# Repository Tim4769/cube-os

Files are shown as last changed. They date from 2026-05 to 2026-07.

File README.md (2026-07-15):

# Cube OS

## Members

- Tim
- Pat
- Taiyo

## Description

Cube OS is a desktop robot of 80 x 80 x 80 mm controlled by two legs. It can walk and communicate with other Cube OS robots through online servers using a custom PCB with an ESP32 microcontroller. It supports voice messages, text messages, and remote control features, helping friends stay connected even when they are far apart.

## Features

- Wi-Fi communication between robots via an online server.
- Two 9 g servos power a four-bar walking linkage for bipedal locomotion.
- IMU-assisted stepping, turning, fall detection, and recovery for inertial gait control.
- Ambient Rest Mode with light-aware quiet, privacy, and do-not-disturb behavior.
- Desk climate sensing for local humidity and temperature data.
- Voice Mailbox using the integrated microphone and speaker to record and replay voice notes from friends.
- USB-C power workflow for battery-powered operation, serial debugging, charging, and flashing.
- Camera sharing with OV2640 pictures or brief videos sent to friends or the dashboard.
- Four-face display OS with widgets, expressions, friend feeds, time, status, and air data.
- Remote control so friends can control another Cube OS and interact from far away.

## Justification

Some of our team members are graduating from high school and heading to college after 7 years together at the same school, and we thought, why do not we build something to keep our connection more real and maintain our friend group? Social media and group chats alone make it hard to keep the connection physical, and we will not always have time to fly to each other's cities to meet.

With Cube OS, we aim to keep annoying each other like we used to, in a friendly manner, by controlling each other's robots and sending random noises and messages at 2 am, like crashing into each other's dorm rooms as we used to. With its extra features, it can also serve as a handy desktop companion for productivity or just an accessory for your desk.

## BOM Breakdown

| Item | Qty | Estimate |
| --- | ---: | ---: |
| PCB, minimum production amount | 2 | 144 USD |
| 9 g micro servo motors | 2 | 8 USD |
| OV2640 camera | 1 | 5 USD |
| AS02504AR speaker | 1 | 5 USD |
| 1S 3.7 V LiPo battery | 1 | 6 USD |
| ER-TFT1.54-2 display panels | 4 | 24 USD |
| **Total** |  | **192 USD** |

## Current Status Photos

Mechanical linkage current status

Current mechanical linkage prototype.

PCB current status

Current PCB layout and component placement.

Assembled Cube OS Rev A PCB current status

Current assembled Rev A PCB during USB, firmware, and Wi-Fi power bring-up.

## Project Files

Short index of the main current files. Directory paths, placeholder files, metadata files, scaffold code, TODO files, and planning notes are intentionally excluded.

- PCB source: `PCB/Rev A/source/Cube OS/Cube OS.kicad_pro`, `PCB/Rev A/source/Cube OS/Cube OS.kicad_sch`, `PCB/Rev A/source/Cube OS/Cube OS.kicad_pcb`
- PCB fabrication package: `PCB/Rev A/gerbers/Gerber.zip`, `PCB/Rev A/production/BOM.csv`, `PCB/Rev A/production/CPL.csv`, `PCB/Rev A/production/fabrication_notes.md`
- PCB order package: `PCB/Rev A/order/BOM_manufacture.xls`, `PCB/Rev A/order/ordering contract.pdf`
- PCB 3D export and linked models: `PCB/Rev A/3d_models/PCB 3d model.step`, `PCB/Rev A/source/Cube OS/3D models/`
- Firmware bring-up: `Firmware/platformio.ini`, `Firmware/src/main.cpp`, `Firmware/src/config.h`, `Firmware/src/`
- Sourcing and budget: `BOM/bom.csv`, `BOM/sourcing_notes.md`
- Mechanical assembly: `CAD/Legs/Linkage V2/Assembly/Stepping foot linkage prototype v2.step`
- Current status photos: `Media/Mechanical status 20260511222505_905_44.jpg`, `Media/PCB status 2026-05-28 at 6.02.45 PM.png`, `Media/PCB status 2026-07-15 at 9.23.13 PM.jpg`

## Git LFS

Large binary project assets are tracked with Git LFS through `.gitattributes`, including status photos, CAD/STEP exports, Gerber/drill manufacturing files, archives, PDFs, and spreadsheet order records.

## Placeholder, Scaffold, And Planning Content

These paths are not listed as active project files because they currently contain placeholder files, metadata files, TODO-only files, scaffold code, or planning notes. There is no final project content inside them yet.

- `Software/`
- `Software/src/`
- `Software/screenshots/`

Also excluded from the active project list: `CAD/Legs/Linkage V2/Components/Placeholder Bar.step`.

## License

MIT. See `LICENSE`.

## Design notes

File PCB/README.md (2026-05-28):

# PCB

Cube OS Rev A electrical design, KiCad source, Gerbers, PCBA files, footprints, and linked STEP models.

## Rev A

- Project: `Cube OS`
- KiCad: 9.0
- Board: 60.05 mm x 60.05 mm, 4-layer FR4, 1.599 mm
- Finish: HAL lead-free
- Assembly: top-side SMT and connectors
- Fabrication archive: `Rev A/gerbers/Gerber.zip`
- Order package: `Rev A/order/`

## Active Files

- Source: `Rev A/source/Cube OS/`
- BOM: `Rev A/production/BOM.csv`
- CPL: `Rev A/production/CPL.csv`
- Notes: `Rev A/production/fabrication_notes.md`
- Gerbers: `Rev A/gerbers/Gerber/`
- 3D board export: `Rev A/3d_models/PCB 3d model.step`
- Order records: `Rev A/order/`
- Template/reference data: `Template/`

## Electronics

| Area | Parts |
| --- | --- |
| MCU | ESP32-S3-WROOM-1-N8R8 |
| Displays | Four display FPCs |
| Camera | OV2640 via Amphenol F32R connector |
| Sensors | SHT45, VEML7700, ISM330DHCX, ICS-43434, 10 kOhm NTC |
| Audio | MAX98357A I2S amplifier, JST speaker connector |
| Motion | Two 3-pin servo headers |
| Power | USB-C, 1S LiPo, BQ24074, TPS63802, LDLN025M25R, TPS7A0212 |
| Controls | JS202011JAQN, SPPJ320600 |

## Production Snapshot

- BOM line items: 38
- CPL top-side placements: 45, excluding H1-H4 mounting holes
- Local footprints: `Rev A/source/Cube OS/Cube_OS_Footprint.pretty/`
- Local STEP models: `Rev A/source/Cube OS/3D models/`

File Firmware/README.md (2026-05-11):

# Firmware

PlatformIO starter firmware for Cube OS on ESP32-S3 Arduino.

## Commands

```bash
pio run
pio run --target upload
pio device monitor
```

## Next Firmware Targets

- Rev A pin map from KiCad nets
- I2C scan: SHT45, VEML7700, ISM330DHCX
- Display test: four SPI faces
- Audio test: ICS-43434 mic and MAX98357A speaker
- Camera test: OV2640 capture
- Motion test: dual servo gait sweep
- Network test: Wi-Fi, server pairing, telemetry

Update `platformio.ini`, `src/config.h`, and `src/main.cpp` as Rev A bring-up replaces the starter code.

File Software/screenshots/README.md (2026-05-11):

# Screenshots

No dashboard screenshots are committed yet.

Expected later: pairing, chat, camera preview, telemetry, and settings screenshots.

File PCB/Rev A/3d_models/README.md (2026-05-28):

# Rev A PCB 3D Models

Rev A board-level 3D export.

- STEP export: `PCB 3d model.step`
- Generated from the Rev A KiCad board for mechanical fit checks.

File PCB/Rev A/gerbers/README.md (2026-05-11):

# Rev A Gerbers

Rev A fabrication exports.

- Archive: `Gerber.zip`
- Source folder: `Gerber/`
- Use with `../production/BOM.csv`, `../production/CPL.csv`, and `../production/fabrication_notes.md`.

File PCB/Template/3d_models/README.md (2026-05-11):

# Template PCB 3D Models

Reference render-export structure only. No actual template 3D render files are committed here.

Active Rev A render exports live in `../../Rev A/3d_models/`.

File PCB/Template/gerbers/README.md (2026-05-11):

# Template Gerbers

Reference fabrication-export structure only.

Active Rev A files live in `../../Rev A/gerbers/`.

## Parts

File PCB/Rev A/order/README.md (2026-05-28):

# Rev A Order Package

Manufacturer-facing order records for the Rev A PCB build.

- Manufacturing BOM: `BOM_manufacture.xls`
- Ordering contract: `ordering contract.pdf`
- Use with `../gerbers/Gerber.zip`, `../production/BOM.csv`, and `../production/CPL.csv`.

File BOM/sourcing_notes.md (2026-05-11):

# Sourcing Notes

## Suppliers

- PCB: current team estimate is 144 USD for the minimum production quantity of 2 boards. Confirm whether this includes assembly, components, shipping, taxes, and tooling before final budget submission.
- Servos: [MakerTech Store 9g micro servo motors](https://www.makertechstore.com/products/9g-micro-servo-motor), 2 required.
- Camera: [Taidacent OV2640 module](https://www.amazon.com/Taidacent-Million-Wide-Angle-Interface-Standard/dp/B08XJZZ287/ref=sr_1_1?sr=8-1), 1 required.
- Speaker: [PUI Audio AS02504AR](https://www.digikey.ch/en/products/detail/pui-audio-inc/AS02504AR/24385606), 1 required.
- Battery: [1S 3.7 V LiPo battery](https://www.kiwi-electronics.com/en/lithium-polymer-li-po-battery-3-7v-500mah-2200?country=), 1 required.
- Displays: [ER-TFT1.54-2 display panels](https://www.ebay.com/itm/306891693859), 4 required.

## Alternatives

- Servo alternatives must fit the mechanical linkage torque, horn, screw, and package constraints. Verify stall current before connecting to the Rev A servo rail.
- Camera alternatives must match the OV2640 FPC pinout or require a PCB/adapter change.
- Speaker alternatives should match the amplifier load, enclosure volume, grille design, and connector.
- Battery alternatives must match 1S LiPo chemistry, protection requirements, JST connector/polarity, enclosure size, and charger current.
- Display alternatives must match the FPC pinout, voltage, controller, active area, and mounting orientation.

## Shipping Notes

- Known sourced-item subtotal from the current breakdown is 192 USD before unlisted parts, shipping, taxes, spare parts, print material, tools, and failed prototypes.
- Order extra servos, displays, FPC cables/modules, and fasteners if the budget allows; these are likely to fail or wear during gait testing.
- Recheck all prices, stock, shipping time, and import fees before final ordering.

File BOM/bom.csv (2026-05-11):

Item | Reference | Qty | Unit Cost | Total Cost | Supplier | Link | Notes
PCB minimum production order | PCB | 2 | 72.00 | 144.00 | TBD | TBD | Team estimate; confirm quote details before ordering
9g micro servo motors | M1 M2 | 2 | 4.00 | 8.00 | MakerTech Store | https://www.makertechstore.com/products/9g-micro-servo-motor | Drives the two leg linkages
OV2640 camera | CAM1 | 1 | 5.00 | 5.00 | Amazon/Taidacent | https://www.amazon.com/Taidacent-Million-Wide-Angle-Interface-Standard/dp/B08XJZZ287 | Camera module for clips or snapshots
AS02504AR speaker | LS1 | 1 | 5.00 | 5.00 | DigiKey | https://www.digikey.ch/en/products/detail/pui-audio-inc/AS02504AR/24385606 | Speaker for voice notes and alerts
1S 3.7 V LiPo battery | J1 | 1 | 6.00 | 6.00 | Kiwi Electronics | https://www.kiwi-electronics.com/en/lithium-polymer-li-po-battery-3-7v-500mah-2200?country= | Battery size and connector fit still need mechanical confirmation
ER-TFT1.54-2 display panels | U7 U9 U10 U12 | 4 | 6.00 | 24.00 | eBay | https://www.ebay.com/itm/306891693859 | Four face/display panels

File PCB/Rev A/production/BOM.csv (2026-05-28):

Reference | Qty | Value | Footprint | Datasheet | JLCPCB
C1,C7,C8,C9 | 4 | 1 uF | Capacitor_SMD:C_0402_1005Metric | ~ | C52923
C2,C3 | 2 | 22 uF | Capacitor_SMD:C_0603_1608Metric | ~ | C59461
C4 | 1 | 10 uF | Capacitor_SMD:C_0402_1005Metric | ~ | C15525
C5,C6 | 2 | 0.1 uF | Capacitor_SMD:C_0402_1005Metric | ~ | C1525
C10 | 1 | 4.7uF | Capacitor_SMD:C_0402_1005Metric | ~ | C23733
C11 | 1 | 47uF | Capacitor_SMD:C_0805_2012Metric | ~ | C16780
CAM1 | 1 | OV2640 | Cube_OS_Footprint:AMPHENOL_F32R-1A7H1-11024 |  | C3167938
H1,H2,H3,H4 | 4 | MountingHole | MountingHole:MountingHole_2.2mm_M2 | ~
J1 | 1 | 1S 3.7 V LiPo | Connector_JST:JST_PH_B2B-PH-K_1x02_P2.00mm_Vertical | ~ | C131337
J2 | 1 | KH-TYPE-C-16P | Cube_OS_Footprint:CONN_KH-TYPE-C_SKE | KH-TYPE-C-16P | C709357
L1 | 1 | 470nH | Cube_OS_Footprint:IND_MWSA0603S_SNL | ~ | C408439
LS1 | 1 | Speaker | Connector_JST:JST_PH_B2B-PH-K_1x02_P2.00mm_Vertical | ~ | C131337
M1,M2 | 2 | Motor_Servo | Connector_PinHeader_2.54mm:PinHeader_1x03_P2.54mm_Vertical | http://forums.parallax.com/uploads/attachments/46831/74481.png | C49257
MK1 | 1 | ICS-43434 | Sensor_Audio:InvenSense_ICS-43434-6_3.5x2.65mm | https://www.invensense.com/wp-content/uploads/2016/02/DS-000069-ICS-43434-v1.2.pdf | C5656610
Q1 | 1 | AO3400A | Package_TO_SOT_SMD:SOT-23 | http://www.aosmd.com/pdfs/datasheet/AO3400A.pdf | C20917
R1,R2,R14,R15,R16,R20,R21,R22,R24 | 9 | 10 kΩ | Resistor_SMD:R_0402_1005Metric | ~ | C25744
R3,R4 | 2 | 5.1 kΩ | Resistor_SMD:R_0402_1005Metric | ~ | C25905
R5 | 1 | 3.3 kΩ | Resistor_SMD:R_0402_1005Metric | ~ | C25890
R6 | 1 | 3.9kΩ | Resistor_SMD:R_0603_1608Metric | ~ | C23018
R7 | 1 | 3.0 kΩ | Resistor_SMD:R_0603_1608Metric | ~ | C4211
R8 | 1 | 510kΩ | Resistor_SMD:R_0603_1608Metric | ~ | C23192
R9 | 1 | 91kΩ | Resistor_SMD:R_0603_1608Metric | ~ | C23265
R10,R12,R13,R25 | 4 | 100kΩ | Resistor_SMD:R_0402_1005Metric | ~ | C25741
R11 | 1 | 1kΩ | Resistor_SMD:R_0402_1005Metric | ~ | C11702
R17,R18,R19,R23 | 4 | 10Ω | Resistor_SMD:R_0603_1608Metric | ~ | C22859
SW1 | 1 | JS202011JAQN | Cube_OS_Footprint:SWITCH_011CQN | JS202011JAQN | C221662
SW2 | 1 | SPPJ320600 | Cube_OS_Footprint:SPPJ320600_AAL | SPPJ320600 | C470431
SW3 | 1 | RESET | Cube_OS_Footprint:SW_TS-1088_XNP | ~ | C720477
SW4 | 1 | BOOT | Cube_OS_Footprint:SW_TS-1088_XNP | ~ | C720477
TH1 | 1 | 10 kΩ NTC thermistor | Resistor_SMD:R_0402_1005Metric | ~ | C77131
TP1 | 1 | GND | TestPoint:TestPoint_Pad_1.0x1.0mm | ~
TP2 | 1 | USB_VBUS | TestPoint:TestPoint_Pad_1.0x1.0mm | ~
TP3 | 1 | BAT_IN | TestPoint:TestPoint_Pad_1.0x1.0mm | ~
TP4 | 1 | ESP32_EN | TestPoint:TestPoint_Pad_1.0x1.0mm | ~
TP5 | 1 | Buck_IN | TestPoint:TestPoint_Pad_1.0x1.0mm | ~
TP6 | 1 | Buck_OUT_3.3V | TestPoint:TestPoint_Pad_1.0x1.0mm | ~
TP7 | 1 | ESP32_BOOT | TestPoint:TestPoint_Pad_1.0x1.0mm | ~
TP8 | 1 | I2C_SDA | TestPoint:TestPoint_Pad_1.0x1.0mm | ~
TP9 | 1 | I2C_SCL | TestPoint:TestPoint_Pad_1.0x1.0mm | ~
TP10 | 1 | CHG_PGOOD | TestPoint:TestPoint_Pad_1.0x1.0mm | ~
TP11 | 1 | CHG_STAT | TestPoint:TestPoint_Pad_1.0x1.0mm | ~
TP12 | 1 | DISP_SCLK | TestPoint:TestPoint_Pad_1.0x1.0mm | ~
TP13 | 1 | DISP_MOSI | TestPoint:TestPoint_Pad_1.0x1.0mm | ~
TP14 | 1 | DISP_BL_PWM | TestPoint:TestPoint_Pad_1.0x1.0mm | ~
U1 | 1 | ESP32-S3-WROOM-1-N8R2 | Cube_OS_Footprint:ESP32-S3-WROOM-1_EXP | ESP32-S3-WROOM-1-N16 | C2913204
U2 | 1 | SHT45-AD1B-R2_Temp_Hu | Cube_OS_Footprint:SHT4x_SEN | SHT45-AD1B-R2 | C5221601
U3 | 1 | VEML7700-TT_SHORT | Cube_OS_Footprint:XDCR_VEML7700-TT |  | C1850416
U4 | 1 | LDLN025J28R | Cube_OS_Footprint:FLIPCHIP4_0P658X0P658_STM | https://www.st.com/resource/en/datasheet/ldln025.pdf | C2971613
U5 | 1 | ISM330DHCXTR_GYRO | Cube_OS_Footprint:LGA-14L_STM | https://www.st.com/resource/en/datasheet/ism330dhcx.pdf | C2655101
U7 | 1 | TCA6408ARGTR | Cube_OS_Footprint:RGT16_1P45X1P45 | https://www.ti.com/lit/gpn/tca6408a | C181499
U8 | 1 | BQ24074RGTR_Batt | Cube_OS_Footprint:RGT16_1P7X1P7 | https://www.ti.com/lit/gpn/bq24074 | C54313
U9 | 1 | Front Display | Cube_OS_Footprint:CON_5034801200_MOL | https://www.buydisplay.com/download/manual/ER-TFT1.54-2_Datasheet.pdf | C587969
U10 | 1 | Right Display | Cube_OS_Footprint:CON_5034801200_MOL | https://www.buydisplay.com/download/manual/ER-TFT1.54-2_Datasheet.pdf | C587969
U11 | 1 | Display | Cube_OS_Footprint:CON_5034801200_MOL |  | C587969
U12 | 1 | Left Display | Cube_OS_Footprint:CON_5034801200_MOL | https://www.buydisplay.com/download/manual/ER-TFT1.54-2_Datasheet.pdf | C587969
U13 | 1 | MAX98357AETE+T | Cube_OS_Footprint:21-0136I_T1633-4_MXM | MAX98357AETE+T | C910544
U14 | 1 | TPS63802DLAR | Cube_OS_Footprint:DLA0010A | https://www.ti.com/lit/gpn/tps63802 | C2845237
U16 | 1 | TPS7A0212PDBVR | Cube_OS_Footprint:SOT23_DBV_TEX | https://www.ti.com/lit/gpn/tps7a02 | C5220172

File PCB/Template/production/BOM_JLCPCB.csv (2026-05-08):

Comment | Designator | Footprint | LCSC Part #
TODO | U1 | TODO | TODO

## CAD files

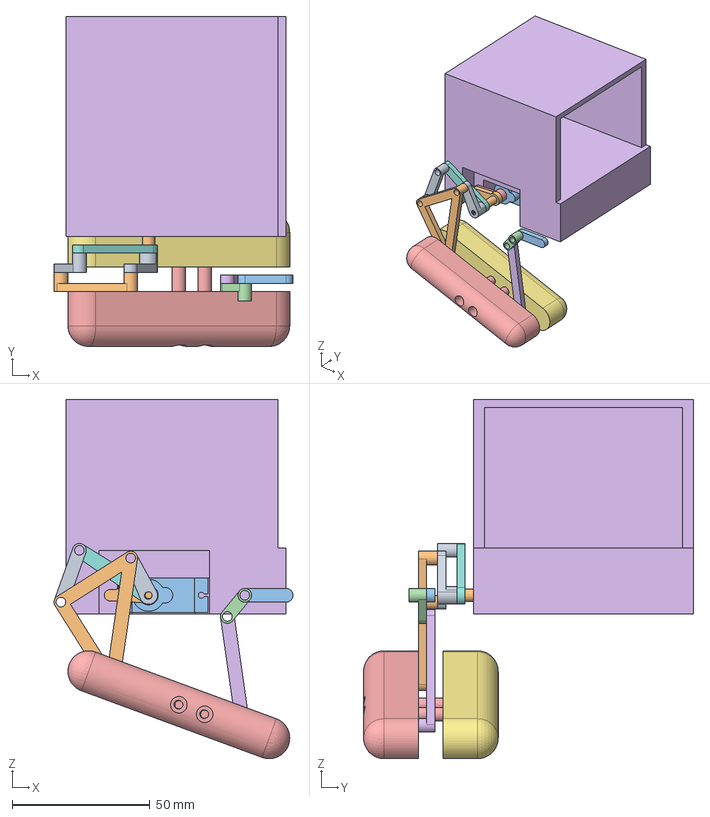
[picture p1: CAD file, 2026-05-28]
CAD/Body/Body v1/Assembly/Full robot assembly v1.step
86.9 x 120.0 x 130.7 mm
Front Lower Link
Front Triangle Coupler
Placeholder Bar
Rear Short Bar
Outside Foot
Rear Long Bar
Inside Foot
Ground Bar v2
Front pivot v2
Motor attachment
servo
splined-drive
horn

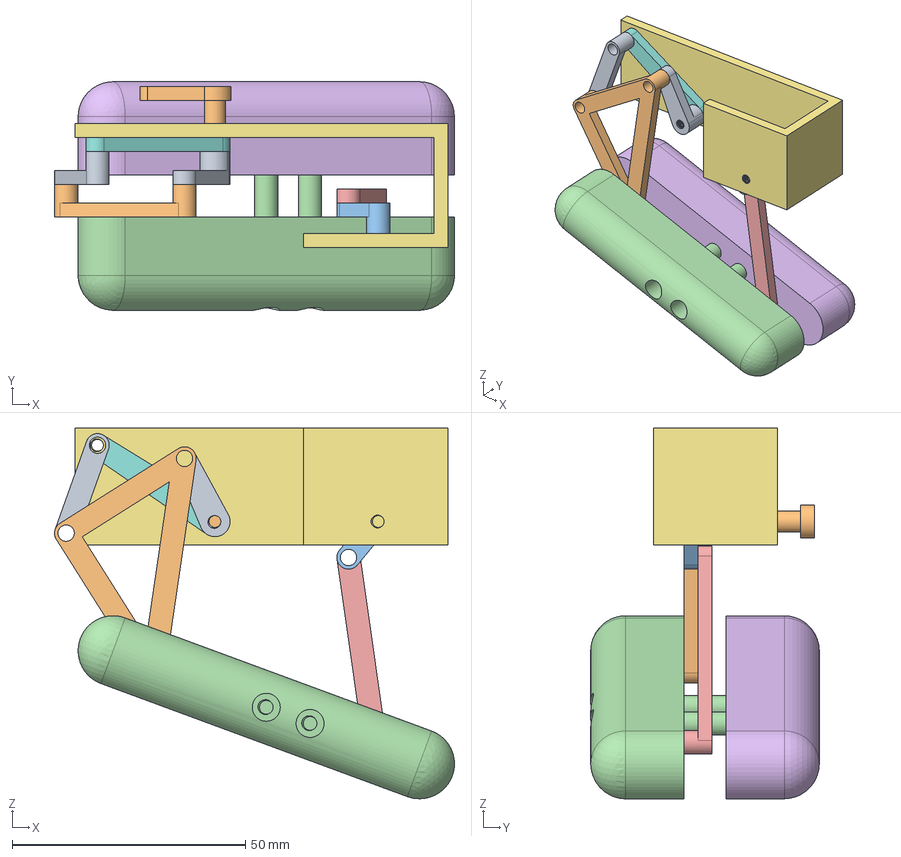
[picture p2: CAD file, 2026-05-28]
CAD/Legs/Linkage V3/Assembly/Stepping foot linkage prototype v3.step
85.7 x 49.0 x 79.4 mm
Front Lower Link
Front Triangle Coupler
Rear Short Bar
Outside Foot
Rear Long Bar
Inside Foot
Test Fixer
Ground Bar v2
Front pivot v2
Motor attachment

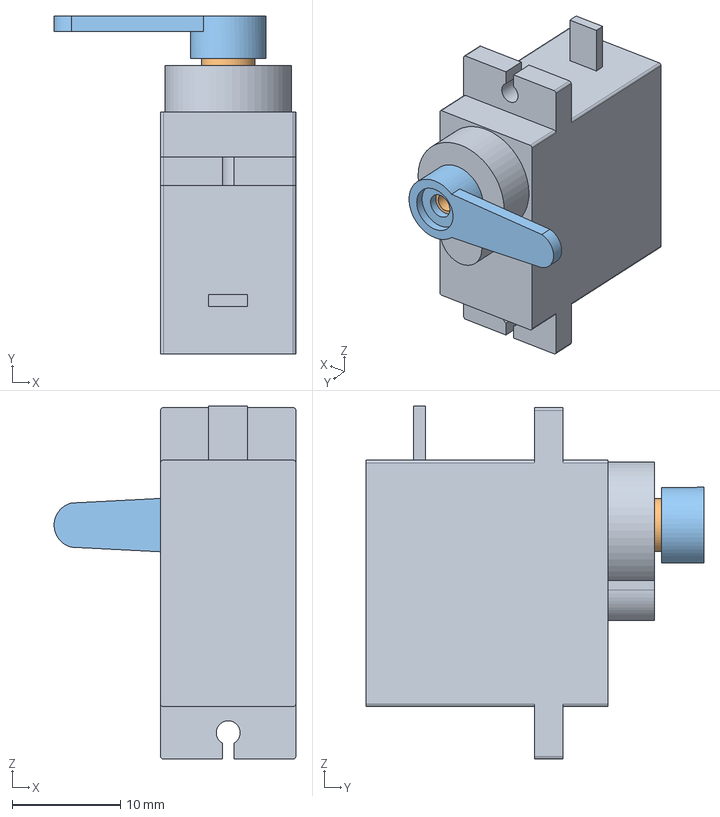
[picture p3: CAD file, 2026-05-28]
CAD/Body/Body v1/Components/_SG90+9g+Micro+Servo.e43d2cae-f814-41ba-8a0c-7b5be9030956 v2.step
22.3 x 31.2 x 32.6 mm
servo
splined-drive
horn

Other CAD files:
CAD/Body/Body v1/Components/Body.step
CAD/Legs/Linkage V3/Components/Front pivot v2.step
PCB/Rev A/source/Cube OS/3D models/SW_TS-1088_XNP.step
CAD/Legs/Linkage V3/Components/Rear Short Bar.step
PCB/Rev A/source/Cube OS/3D models/F32R-1A7H1-11024--3DModel-STEP-56544.STEP
CAD/Legs/Linkage V3/Components/Rear Long Bar.step
PCB/Rev A/source/Cube OS/3D models/RGT0016A.stp
CAD/Legs/Linkage V3/Components/Placeholder Bar.step
PCB/Rev A/source/Cube OS/3D models/DLA0010A.stp
CAD/Legs/Linkage V3/Components/Front Lower Link.step
PCB/Rev A/source/Cube OS/3D models/AMPLA7030SR47MT--3DModel-STEP-368357.STEP
CAD/Legs/Linkage V3/Components/Inside Foot.step
PCB/Rev A/source/Cube OS/3D models/SHT4x_SEN.step
CAD/Legs/Linkage V3/Components/Front Triangle Coupler.step
PCB/Rev A/source/Cube OS/3D models/LGA-14L_STM.step
CAD/Legs/Linkage V1/B1.step
CAD/Legs/Linkage V1/B2.step
CAD/Legs/Linkage V1/B3.step
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

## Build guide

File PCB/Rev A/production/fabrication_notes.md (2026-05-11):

# Fabrication Notes

## Board

- Layers: 4-layer FR4
- Thickness: 1.599 mm in the KiCad stackup
- Finish: HAL lead-free in the KiCad stackup
- Copper: 35 um outer layers, 17 um inner layers in the KiCad stackup
- Board outline: approximately 60 mm x 60 mm, with a left-side edge cutout
- Solder mask: manufacturer default unless a final color is specified before ordering
- Silkscreen: manufacturer default unless a final color is specified before ordering

## Assembly

- Assembly side is top-side SMT plus top-side connectors.
- Confirm whether the assembly house will place the USB-C connector, JST connectors, servo pin headers, FPC connectors, microphone, and switches, or whether some parts should be hand-soldered after PCBA.
- Verify display/camera FPC connector orientation before ordering.
- Verify servo header orientation against the enclosure and linkage CAD before soldering.
- Mounting holes H1-H4 are mechanical features, not BOM placement items.

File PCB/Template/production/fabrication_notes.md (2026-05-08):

# Fabrication Notes

## Board

- Layers: TODO
- Thickness: TODO
- Finish: TODO
- Solder mask: TODO
- Silkscreen: TODO

## Assembly

- TODO: Note any hand-soldered parts, DNP parts, or special assembly instructions.

## Checks

- TODO: Record DRC/ERC status before ordering.

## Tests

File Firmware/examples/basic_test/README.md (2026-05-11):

# Basic Test

Minimal Rev A bring-up sketch area.

- Serial boot log
- Status LED or debug GPIO
- Rail checks
- Button/switch reads
- Sensor, display, audio, camera, and servo smoke tests

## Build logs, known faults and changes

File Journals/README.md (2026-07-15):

# Cube OS Journals

This folder contains the entries split from `cube-os-journal.md`, exported on 2026-07-15, together with later project journal entries.

## Authors

- [Pat](./Pat/) (`chawanvitpat`): 9 entries
- [Tim](./Tim/) (`timwang007`): 18 entries, including the 2026-07-15 PCB bring-up journal

Each entry is stored as a separate Markdown file named by its creation date. Tim has two entries on both 2026-05-04 and 2026-05-06, so those four filenames also include their UTC creation times to prevent collisions. Original attachment and recording links from the exported entries are preserved.

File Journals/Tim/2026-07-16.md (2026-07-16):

# Journal — 2026-07-16

- Author: Tim (`timwang007`)
- Created at: 2026-07-16

Continued testing the Rev A PCB while waiting for the correct battery cable. Yesterday's oscilloscope measurements showed that Wi-Fi startup pulled TP6 from around 3.3V down to around 2V, so today I wanted to find out whether the rest of the ESP32 and PCB worked normally when Wi-Fi was disabled.

I temporarily disabled all Wi-Fi credential, access-point, mDNS, and web-server startup code. I also explicitly turned the radio off with:

```cpp
WiFi.mode(WIFI_OFF);
```

At first I disabled the movement setup too, but then I re-enabled `setupMovement()` so I could test the two servo PWM outputs while keeping Wi-Fi off. The firmware printed:

```text
PWM test active: movement enabled and Wi-Fi disabled.
```

With this firmware running, I checked TP5 and TP6 again. Both rails stayed stable with PWM active and Wi-Fi disabled:

- TP5 remained near its normal USB-powered level
- TP6 remained near 3.3V
- USB stayed connected
- The falling-edge triggers did not capture another large voltage collapse

This isolated the earlier reset more clearly. The ESP32, 3.3V regulator, and PWM hardware can run normally without Wi-Fi. The major voltage collapse appears when the Wi-Fi radio starts and creates the larger current transient.

I then measured pad 1 of both servo connectors with the FNIRSI DSO-510. On both M1 and M2, pad 1 is the PWM signal, pad 2 is `+BAT`, and pad 3 is GND. I used the connector GND as the oscilloscope reference and measured pad 1 with the servos disconnected.

The results were:

- M2 pad 1: 50Hz, 7.45% duty cycle, around 3.22V peak-to-peak
- M1 pad 1: 50Hz, 7.50% duty cycle, around 3.22V peak-to-peak
- Both duty cycles correspond to a pulse width of approximately 1.5ms, which is the expected servo center signal

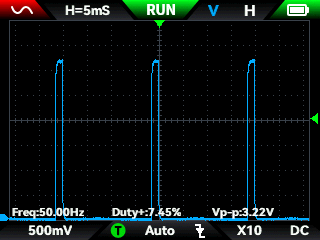
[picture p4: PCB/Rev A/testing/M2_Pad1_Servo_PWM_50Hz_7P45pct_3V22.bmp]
M2 pad 1 servo PWM


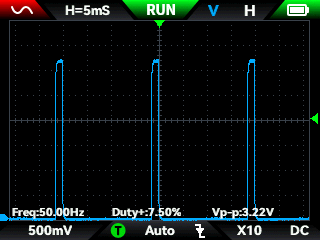
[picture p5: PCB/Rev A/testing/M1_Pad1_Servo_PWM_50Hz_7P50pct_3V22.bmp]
M1 pad 1 servo PWM


This confirmed that the 14-bit ESP32-S3 LEDC configuration works and that both PWM signals reach their correct connector pads. I did not connect physical servos because their middle connector pins use `+BAT`, and I am still waiting for the battery adapter.

After the power and PWM tests passed, I started adding a separate sensor module. I created `Sensors.h` and `Sensors.cpp` so sensor code would stay separate from movement, networking, and the main firmware control flow.

The first test was an I2C scanner. The Rev A I2C bus uses:

```cpp
constexpr int I2C_SDA_PIN = 8;
constexpr int I2C_SCL_PIN = 9;
```

I started the bus at the standard 100kHz speed:

```cpp
bool started = Wire.begin(I2C_SDA_PIN, I2C_SCL_PIN, 100000);
```

The scanner checks normal I2C addresses from 1 through 126. For every address, it begins an empty transmission and checks the result returned by `Wire.endTransmission()`. A result of zero means a device acknowledged the address.

The expected Rev A devices are:

- `0x10`: VEML7700 ambient-light sensor
- `0x20`: TCA6408 GPIO expander
- `0x44`: SHT45 temperature and humidity sensor
- `0x6A`: ISM330DHCX accelerometer and gyroscope

I added a small `switch` function that converts each known numeric address into a readable device name. I kept the scanner output simple and removed the extra leading-zero formatting because it did not change the scan itself.

While writing the scanner, I learned several C++ concepts:

- Headers from Arduino and installed libraries normally use angle brackets, such as `#include <Wire.h>`
- Project headers normally use quotation marks, such as `#include "Sensors.h"`
- `const char*` represents a pointer to read-only character data, which is how the device-name function returns fixed text
- A `switch` compares one value with several exact `case` values
- `0x` marks a hexadecimal number in source code, while `HEX` tells `Serial.print()` how to display an existing number
- `uint8_t` is an unsigned 8-bit integer from 0 to 255, which is large enough for an I2C address
- `unsigned long` is used for larger positive values such as the result of `millis()`
- `Serial.print()` stays on the current output line, while `Serial.println()` finishes the line

I then added the ISM330DHCX driver using the chip-specific class supplied inside Adafruit's larger LSM6DS-family library:

```cpp
#include <Adafruit_ISM330DHCX.h>

Adafruit_ISM330DHCX imu;
```

The physical sensor is an ISM330DHCX. The installed package is named `Adafruit LSM6DS` because Adafruit groups several related ST sensors into one library and shares their common accelerometer and gyroscope code.

I added two state variables:

```cpp
bool imuReady = false;
unsigned long lastImuPrintTime = 0;
```

`imuReady` prevents the firmware from reading the IMU unless initialization succeeds. `lastImuPrintTime` remembers the previous print time so measurements can be printed every 250ms without using a blocking `delay()`.

The initialization code connects to address `0x6A` using the existing I2C bus:

```cpp
if (!imu.begin_I2C(IMU_ADDRESS, &Wire)) {
  Serial.println("Failed to initialize ISM330DHCX");
  return;
}

imuReady = true;
```

The `!` reverses the Boolean result, so the error block runs only when `begin_I2C()` returns false. The `return` exits sensor setup after a failure, so `imuReady = true` is reached only after successful initialization.

I configured the IMU for basic hand movement and tilt testing:

```cpp
imu.setAccelRange(LSM6DS_ACCEL_RANGE_4_G);
imu.setGyroRange(LSM6DS_GYRO_RANGE_500_DPS);
imu.setAccelDataRate(LSM6DS_RATE_104_HZ);
imu.setGyroDataRate(LSM6DS_RATE_104_HZ);
```

The repeating update function uses this non-blocking timing check:

```cpp
unsigned long now = millis();

if (now - lastImuPrintTime < IMU_PRINT_INTERVAL_MS) {
  return;
}

lastImuPrintTime = now;
```

If less than 250ms has passed, the function returns immediately. Once 250ms has passed, it saves the new time and reads another sample.

The Adafruit driver fills three `sensors_event_t` containers:

```cpp
sensors_event_t acceleration;
sensors_event_t gyro;
sensors_event_t temperature;

imu.getEvent(&acceleration, &gyro, &temperature);
```

The `&` passes the memory address of each container so `getEvent()` can place new measurements inside it. Values are then accessed through fields such as:

```cpp
acceleration.acceleration.x
gyro.gyro.x
temperature.temperature
```

The repeated `gyro.gyro.x` naming is because the first `gyro` is my event variable, the second is the gyro section inside the generic Adafruit event structure, and `x` is the axis value. The IMU temperature is the chip's internal temperature and is not as suitable for room-temperature measurement as the separate SHT45.

I found and fixed several code problems while integrating the module:

- `scanI2CBus()` was missing its closing brace, which accidentally placed later function definitions inside it
- An IMU error `Serial.println()` was missing its final semicolon
- `Wire.begin()` was being called in both `setupSensors()` and `scanI2CBus()`, so I removed the duplicate call from the scanner
- `updateSensors()` needed to be called from `firmwareLoop()` for repeated measurements
- `setupSensors()` was temporarily missing from `firmwareSetup()`, so `imuReady` stayed false and `updateSensors()` immediately returned

The missing `setupSensors()` call caused a confusing test. PlatformIO uploaded successfully, and Device Monitor showed all the PWM messages, but no sensor messages appeared. The correct startup sequence is:

```cpp
setupSensors();
```

inside `firmwareSetup()`, followed by:

```cpp
updateSensors();
```

inside `firmwareLoop()`.

The USB port also appeared as `/dev/cu.usbmodem1101` instead of the earlier `/dev/cu.usbmodem101`. This is normal for native USB because macOS can assign a different device name when the ESP32 resets, switches between bootloader and firmware modes, or reconnects. `pio device list` shows the current port.

After restoring `setupSensors()`, uploading again, and opening Device Monitor at 115200 baud, the sensor code worked. The I2C scan and ISM330DHCX initialization messages appeared, followed by live acceleration, gyroscope, and internal-temperature readings. Tilting and rotating the PCB changed the appropriate values, confirming that the ESP32 can communicate with the onboard IMU and read real measurements.

At the end of today's testing, the confirmed working areas are:

- Stable TP5 and TP6 rails with Wi-Fi disabled
- Native USB upload and serial monitoring
- Both M1 and M2 50Hz PWM outputs
- The shared I2C bus
- ISM330DHCX initialization and live sensor readings

The main unresolved hardware test is still Wi-Fi startup with a correctly connected 1S LiPo battery. Once the battery adapter arrives, I will repeat the TP5 and TP6 startup captures and see whether the battery supplies the short current transient that currently resets the board when it is powered from USB alone.

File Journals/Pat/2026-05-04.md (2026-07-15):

# Journal — 2026-05-04

- Author: Pat (`chawanvitpat`)
- Source entry: 2
- Entry ID: 5491
- Created at: 2026-05-04T20:53:35Z

# Leg mechanism brainstorming

**Objective**: to brainstorm and design an early prototype that would be the base for the walking mechanism of the desk companion robot

**Requirement**: only driven my one motor on each side and should best fit the mood of the robot while maintaining some kind of mobility

## Linkages

Got recommended to check out linkages from the slack so I checked some out through these websites:

https://www.csuohio.edu/sites/default/files/47A-2016.pdf

https://www.diywalkers.com/walker-abcs.html

Advantage

- Rotate continuously clockwise → moving in a predetermined path
- Need to know the length of connection and joint position to simulate the path
- Energy efficient
- Can change the number of linkages to fit desired motion
- Move forward and backwards

Disadvantage

- I am not sure how to move length and right
- Might not fit the vibe of the robot

### 4-bar linkage

- Sturdier and more efficient than higher bar counts
- Higher footpath → better for navigating different terrains and obstacles → avoid jamming
- Lower footpath → sturdier and better for larger walkers
- Reducing number of legs → need to increase the time the foot is in contact with the ground
    - Increasing velocity during the lifting can result in force

Jansen linkage calculator: https://www.diywalkers.com/strandbeest-optimizer-for-lego.html

4-bar linkage calculator: https://www.diywalkers.com/4-bar-walking-linkage.html

**Idea**: the leg can be a 4-bar linkage connected with another fixed joint on the frame of the robot to make a foot

- This was chosen due to its higher simplicity → more solid due to lower amount of connections but still maintain the ability to be customisable

I simulated the 4-bar linkage in the 4-bar linkage calculator, messing around the length and angle parameter until getting the foot pathing I would like → this will become the connection of the front of the foot later on

Photos of the simulation and the documentation of the parameters that are being manipulated:

Screenshot 2026-05-04 at 19.10.26.png

Screenshot 2026-05-04 at 22.50.55.png

Prototype this on Fusion 360 + the other joint to try it out → connect using screws and spacers for joints → allows free rotation

- B2-B4 joint needs to be fixed but the rest needs to be able to move → try this dimension and testing it with the revolving joints and rigid components where necessary

CADed the simulated 4-bar linkage in Fusion 360 with revolute joints which works according to the simulation

Screenshot 2026-05-04 at 22.51.34.png

Then added another 2 bar part which is joined with the tip of this 4-bar linkage to create the portion of the back of the foot → added a large slot as a mock up foot or testing

- The total length of the two bars was chosen so that the foot was flat at the highest point of the 4-bar linkage’s rotation allowing it to rest stably

Screenshot 2026-05-04 at 22.20.19.png

Screenshot 2026-05-04 at 22.52.15.png

Screenshot 2026-05-04 at 22.22.58.png

Simulated driving the crank center to different angles and see that the foot could possibly work, so the next plan will be to 3D print these designed parts and test out an early prototype before moving on with the other parts of the mechanics.

## Recording Links

- https://lookout.hackclub.com/api/media/7777bb0a-96d1-48da-aa41-9f1ff01fe9ee/video.mp4
- https://lookout.hackclub.com/api/media/ca966460-fe87-439b-b9ca-4d178f79ef6e/video.mp4

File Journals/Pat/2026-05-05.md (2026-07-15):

# Journal — 2026-05-05

- Author: Pat (`chawanvitpat`)
- Source entry: 4
- Entry ID: 5634
- Created at: 2026-05-05T20:51:14Z

# Leg design + testing

## Modifications to the original leg design + other mockups

Started with editing the original design as we realised that the original foot as the highest point of the front of the foot will be in the same line as the back the foot will be flat, and will never push down against the ground which is necessary to give the force needed to push the robot forward

Screenshot 2026-05-05 at 22.46.12.png

I decreased the length of the long bar of the back foot so at the highest point of the the front oot there is a slight angle down, allowing the foot to push the robot forward.

I also created a block to mock up the base of the robot so I can fix the frame to it as well as the short bar for the back of the foot for testing.

I then mirrored the foot to the other side for the other leg just for the feeling of the final model and how it should look like → I realized that the legs were way too long and will need to be decreased proportionally in the final design

Screenshot 2026-05-05 at 22.46.35.png

## Simulation of joint relationship

I also used the animate joint relationship to turn the crank joint to simulate the motor spinning the crank joint → I realized that this configuration of the 4-bar linkage can follow 2 possible foot paths which depends on the starting configuration of the leg

- After couple of rotations which is inconsistent in the Fusion 360 simulation it will turn from one foot path to another
- This also could be because solids can phase through each other in the simulation which will not happen in real life
- I decided that this should be resolved with the physical mockup and testing so I left it as it is

Screenshot 2026-05-05 at 22.03.13.png

Screenshot 2026-05-05 at 22.02.23.png

## 3D printing

Slice the file for H2D printer and printed it with the school’s H2D bambu 3D printer that can be later on assembled for testing → no time today for assembling so it is planned for the next time

Screenshot 2026-05-05 at 22.48.35.png

# Main body

Make a main body → decided it will have the dimension of 80*80*80 mm as the PCB that I have talked with Tim will have the dimension of 60*60 which will allow each wall to have 5 mm thickness and 5 mm space in each side for any extra wiring.

Screenshot 2026-05-05 at 22.48.58.png

Screenshot 2026-05-05 at 22.49.16.png

- The bottom is thicker with 15 mm to hold the motor
- The back plate is held to the main body with 4*M3 screws I added threaded holes so the screws can directly be screwed into the print without inserts
- All edges of the cubes except the bottom two on the side are fileted → the two on the bottom side are not fileted as they will be covered by the legs and motor

## Recording Links

- https://lookout.hackclub.com/api/media/518d9b8c-5dba-49f0-9211-4e7a3d3eff14/video.mp4
- https://lookout.hackclub.com/api/media/7defc04d-a913-4f96-b56f-8e44cfee723e/video.mp4

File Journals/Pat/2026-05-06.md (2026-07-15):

# Journal — 2026-05-06

- Author: Pat (`chawanvitpat`)
- Source entry: 6
- Entry ID: 5781
- Created at: 2026-05-06T19:22:28Z

# Assembling and testing linkage

I assembled the 3D printed 4-bar linkage using screws spacers and nuts → I had to align the bars so that nothing collides with each other when the crank bar turns anti clockwise

- I will take this into account when designing the new leg version
- I also need to figure out how to attach the linkage to the motor

Screenshot 2026-05-06 at 21.17.32.png

I realised that the foot part is too thick to be assembled with screws so I decreased the thickness of the foot and printed it again

I also needed to change the configuration of the bars so that the ground bar is furthest back, so that it can be easily attached to the main body while allowing the crank bar to easily be attached and driven by the motor

## Designing the mock up fixer

This can also give an idea of how to actually fix the leg to the main body

I designed a mockup fixer bar to test out the linkage but the first design has a protruding section right next to the crank joint which interferes with the rotation of the crank

Screenshot 2026-05-06 at 10.06.19.png

I then changed the fixer to be longer with the elevating extrusion to be on the other side of the elevated part. I also designed fixer so that the further left and right bar can be fixed on the inside part of the fixer → I can possibly use this design for the final leg.

Screenshot 2026-05-06 at 21.18.37.png

After printing the fixer, I tested out the fixer with the new configuration of the bar → it looks like it would work but the foot will have to be on both side of the linkage so that linkage can hold up the main body by itself. 

Screenshot 2026-05-06 at 21.21.16.png

Screenshot 2026-05-06 at 21.21.59.png

- The elevating extrusion can also be closer to the screw hole for the small bar for the back foot as it only rotates lower than 90 degrees clockwise and anticlockwise
- I also tested the strength of configuration by dropping it from a table height and I tried throwing it down with more force as well as there was no way to yet simulate the load of the body no bars snapped or screw came lose so the linkage can be quite good in terms of strength

# The next step

- redo the new configuration in Fusion 360 so that I can minimize the spacer height so the leg can be less thick while also decreasing the size of the bar all proportionally so that the leg can look smaller on the main body
- I want to try another configuration of the foot path with the tear drop foot path pointing up so instead of the robot moving forward by pushing back. It moves forward by stepping forward and pulling the robot forward instead.
- Continue to work on fitting the electrical components into the body.

## Recording Links

- https://lookout.hackclub.com/api/media/a454e27b-63a1-4b69-98fe-39084f606dd4/video.mp4
- https://lookout.hackclub.com/api/media/cd850387-9e73-4edd-8f72-86c70a18f2d2/video.mp4
- https://lookout.hackclub.com/api/media/0b4e3ece-b488-431e-930f-b42d155ca197/video.mp4
- https://lookout.hackclub.com/api/media/0b928b1f-3743-4d4b-80b0-624a105626f4/video.mp4
- https://lookout.hackclub.com/api/media/1abc9f22-2e23-4cd0-882d-d0a82399aee0/video.mp4

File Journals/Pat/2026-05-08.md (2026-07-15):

# Journal — 2026-05-08

- Author: Pat (`chawanvitpat`)
- Source entry: 9
- Entry ID: 6143
- Created at: 2026-05-08T19:15:08Z

# New linkage simulation and pathing

Instead of the pushing mechanism of the last linkage I want to design another pathing in which the movement will be controlled more by the stepping forward and pulling for the foot

- Simulated and tinkered with the 4-bar linkage calculator until I get the pathing that looks good

Screenshot 2026-05-08 at 21.10.24.png

Using the same proportion and the same logic as before but halving the size from the indicated numbers on screen I get this:

Screenshot 2026-05-08 at 21.10.44.png

The pathing simulated is the same as the one in the calculator, so I added the back foot part

Screenshot 2026-05-08 at 21.11.06.png

The motion looks much more like walking than beforeI also extended the length of the foot proportionally to the length of the leg to expect more stability

I then added an approximation of the main body and mirrors another leg so I can have an idea of how it looks compared to the last version

Screenshot 2026-05-08 at 21.11.26.png

Proportionally it looks way better than before. For stability, I also added another side of the foot so there is more surface area in contact with the ground so it hopefully does not fall when one foot is lifted

Screenshot 2026-05-08 at 21.11.53.png

To connect the two sides of the foot together, I initially wanted to connect it at both ends of the foot but realised that it will collide with the linkages as the robot walks forward and backwards. Instead, I created two holes in the middle of the foot that does not interfere with the linkage and use threaded holes on both sides of the foot so I can later on connect them with screws without nuts or inserts.

Screenshot 2026-05-08 at 21.12.11.png

I then design a fixer just for the testing phase so it can fix the fixed bar in the front portion of the foot as well as the back portion

Screenshot 2026-05-08 at 21.12.29.png

Just to make sure everything fits nicely, I also designed a test block to test whether the threaded holes I made can hold the M3 screws we had and printed it. The result looks good so I continued to print the testing leg portions with the H2D printer using basic PLA as it seems to be strong enough.

Screenshot 2026-05-08 at 21.12.45.png

## Recording Links

- https://lookout.hackclub.com/api/media/1c00f647-e5d8-4561-9cb0-e9c0297854d1/video.mp4

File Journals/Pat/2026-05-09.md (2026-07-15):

# Journal — 2026-05-09

- Author: Pat (`chawanvitpat`)
- Source entry: 11
- Entry ID: 6329
- Created at: 2026-05-09T20:58:27Z

# Assembling and testing v2 linkage

I retrieved the printed parts from the printer and I tried assembling the linkage.

- What worked fine:
    - I first tested out **the connection between the two parts of the feet** which works perfectly fine with the threads holding well the two parts of the legs
    - the **front part linkage of the foot** also works fine with the extra extrusion from the linkage bars to give space for the head of the screw working fine → maybe for further using other heads other than counterbore can decrease the space needed hence decreasing the thickness of the leg
- Problems:
    - The **back foot linkage** encounter the problem where the head of the counterbore screw gets stuck on the testing fixer because the thickness of the screw is three mm but the space is only 2 mm
        - I addressed this by extending the width of the space in the hole of the fixer where the linkage will be hosted, and also increased the spacer at the small bar of the back part to 3.5 mm instead of 2 mm
    - I also realised that I did not model the threads in the connection between the two linkages and the outside part of the foot
        - I just replaced the 3.5 mm diameter hole with the threaded hole for M3 screws instead

I then reprinted the parts that needed editing and assembled it again

Screenshot 2026-05-09 at 22.55.45.png

Everything looks to be working properly with the leg being able to stand by itself with the two side of the feet 

Things to improve:

- I have noticed that **the joint between the rear short bar and rear long bar can flip** towards the front which would make it stuck on the crank joint which would prevent the crank bar from being rotated further
    - This can be fixed by moving the fixing point of the rear linkage backwards or create a flap to prevent the joint from flipping → the former might be simpler
- The **two feet** part also cannot fit in very tightly with the linkages because of the head of the screw that fixes the two linkages with the outside part of the foot
    - For this I can just extend the cylinder that links the two to hide the screw and make the hole cut for the head of the screw on the outside part of the foot deeper, so that a short screw can still hold the foot together

Next steps:

- Edit the parts that need editing and print the mirrored part
- Join the two legs together with a cube that mimics the main body of the CubeOS
- Design the mount for the motor so it can actually drive this linkage

# Documentation

I started the documenting process by exporting each part of the v1 and v2 linkage and manage them into the GitHub folders which Tim set up.

## Recording Links

- https://lookout.hackclub.com/api/media/28682496-b777-4f88-9d91-e40fbe027d2c/video.mp4
- https://lookout.hackclub.com/api/media/d5354533-097a-4448-8b1e-31e8939be5db/video.mp4
- https://lookout.hackclub.com/api/media/038d7f1d-44a1-4dff-8070-fdcf39d52011/video.mp4
- https://lookout.hackclub.com/api/media/c0b2edef-13d5-41bb-b359-f5aa9865204c/video.mp4

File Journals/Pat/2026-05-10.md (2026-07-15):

# Journal — 2026-05-10

- Author: Pat (`chawanvitpat`)
- Source entry: 13
- Entry ID: 6490
- Created at: 2026-05-10T20:31:09Z

# Editing Parts

- Increased the cylinder length by 3 mm so it conceals the whole screw between the two parts of the foot
- I also increased the depth of the hole for the head of the screw by 2mm so it can compensate for the increased cylinder length
- I also increased the distance between the front linkage and the rear linkage so that it does not collide anymore → I simulated to make sure
- I also adjusted the test fixer to accommodate the change

Screenshot 2026-05-10 at 22.22.53.png

Screenshot 2026-05-10 at 22.23.16.png
# Documentation

- I also exported the v1 of the linkage so that people can compare both versions and see the iterations that is being made
- I updated the v2 with the new edits

Screenshot 2026-05-10 at 22.28.13.png
Screenshot 2026-05-10 at 22.28.02.png

## Recording Links

- https://lookout.hackclub.com/api/media/f62ff827-ff66-41d0-a72c-0f7b69ec7a63/video.mp4

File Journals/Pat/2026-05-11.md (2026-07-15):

# Journal — 2026-05-11

- Author: Pat (`chawanvitpat`)
- Source entry: 15
- Entry ID: 6648
- Created at: 2026-05-11T19:46:18Z

# Main Body Brain storming

**What components needs to be housed and mounted (from Resources and Links)**

| Item to order | Qty / location | Link / document | CAD files/ Dimentions | Datasheet |
| --- | --- | --- | --- | --- |
| OV2640 camera | 1 | https://www.arducam.com/arducam-ov2640-camera-module-2mp-mini-ccm-compact-camera-modules-compatible-with-arduino_m0031esp32-esp8266-development-board-with-dvp-24-pin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 | https://grabcad.com/library/ov2640-2 |  |
| Speaker / small acoustic driver | 1 | [PUI Audio AS02504AR specs](https://puiaudio.com/file/specs-AS02504AR.pdf) | https://puiaudio.com/product/speakers-and-receivers/as02504ar |  |
| TS90A 9 g micro servo | 2 | [Stelltron TS90A 9 g micro servo](https://stelltron.education/product/9g-micro-servo-motor-type-ts90a/) | https://www.autodesk.com/community/gallery/project/132949/sg90-9g-micro-servo |  |
| 1S 3.7 V LiPo battery | 1 | [https://www.kiwi-electronics.com/image/catalog/pdf/LP503035 500mAh 3.7V (AD306053) 20230615[34].pdf](https://www.kiwi-electronics.com/image/catalog/pdf/LP503035%20500mAh%203.7V%20%28AD306053%29%2020230615%5B34%5D.pdf) | https://www.kiwi-electronics.com/en/lithium-polymer-li-po-battery-3-7v-500mah-2200?country= |  |
| ER-TFT1.54-2 display panels | 4: top, front, right, left | [ER-TFT1.54-2 display datasheet](https://www.buydisplay.com/download/manual/ER-TFT1.54-2_Datasheet.pdf) | https://www.ebay.com/itm/306891693859 |  |
- The Back panel should be free from directly connecting anything as we want it to be removable for fixing the inside
- OV2640 camera  should be in front
- Should be holes for ventilation + letting the sound out from speaker
- Servo will be under the main box → wired from the button (need to make hole so the wire can connect to the PCB without being exposed
- Box to house the LiPo battery
- Housing all 4 display panels on 4 sides of the Cube (top, front, left, right)

Things that cannot be moved from PCB 

- 2 holes to access the power switch and communication button
- Hole for the USB-C port
- Note: this will all be on one side of the PCB → this side will be directly adjacent to the wall of the main body

Things to get for dimension that are still missing

- Power switch
- Communication switch

Priority:

1. Think of a way to mount the motor → under the main body -> has to be able to drive the crank bar at the crank joint

# Modifying leg to be suitable for servo motor

I modified the Ground Bar and Front pivot to Ground Bar v2 and front pivot v2 that have slightly bigger holes at the crank joint

- This allows the creation of a motor attachment unit with the size of 4.5 mm diameter to be slide in and attached to the front pivot as shown → this will be done using an M3 screws with ISO threads so the motor attachment and front pivot will be rigid but allowing rotation in the joint

Screenshot 2026-05-11 at 21.43.16.png

Screenshot 2026-05-11 at 21.43.54.png

# Next step

1. Look into how to host the motor at the bottom of the main body
2. Look into a hood for the leg part to hide the mechanism
3. Brainstorm layout of the main body for all the components

## Recording Links

- https://lookout.hackclub.com/api/media/d5f9e7f4-8c2d-4d47-a134-bb13728f419d/video.mp4

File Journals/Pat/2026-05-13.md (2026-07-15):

# Journal — 2026-05-13

- Author: Pat (`chawanvitpat`)
- Source entry: 19
- Entry ID: 6982
- Created at: 2026-05-13T20:21:16Z

I started printing the new edited parts designed in 11 May 2025 log.

# Designing Motor holder

Started designing holder for the TS90A 9g micro servo

- I found the f3d file for the motor on the fusion community

Screenshot 2026-05-13 at 22.19.18.png

I edited the motor attachment part so that it can fit nicely with the motor mounter:

Screenshot 2026-05-13 at 22.19.39.png

Then created the mount for the motor which would be the under side of the CubeOS main body

- I designed it so that it will be slid in from the side of the cube for easier assembly and disassembly and will be mounted through the mounting hole directly onto the main body with threads

Screenshot 2026-05-13 at 22.19.58.png
Screenshot 2026-05-13 at 22.20.14.png

The hole I created is to create enough space for the motor to actually spin without getting stuck while also allowing space for a screw driver to access the mounting holes for assembly. I then used assembly features in fusion 360 to properly assemble the motor with the motor attachment and linkages to simulate everything moving and there seems to be no physical clash.

Next Steps:

- Test the newly designed front pivot, ground bar, and motor attachment
- Create a wiring hole for the motor
- The motor holder cannot be tested physically because it will arrive later.
- Start designing the main body with the newly finished PCB to keep in mind need connections like USB-C buttons etc

## Recording Links

- https://lookout.hackclub.com/api/media/c576f782-dcab-439a-9967-bf7aac61d95a/video.mp4

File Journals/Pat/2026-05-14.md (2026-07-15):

# Journal — 2026-05-14

- Author: Pat (`chawanvitpat`)
- Source entry: 21
- Entry ID: 7157
- Created at: 2026-05-14T19:47:43Z

# Main body design and component mount brainstorm

I first wanted to design the main body of the robot with the newly designed motor holder

- To keep the main body a cube with 80 * 80 * 80mm dimensions → I found that I will only have a height of around 55 mm to play with to host all the components as the motor will eat up the rest of the 25 mm

Screenshot 2026-05-14 at 21.43.58.png

I implemented the design I thought about before with the back panel being removable for assembly and any maintenance or fixes that needs to be carried out on the robot.

I then brainstormed the methods to mount the screens as it does not come with mounting holes → I landed with mounting the screen from the inside to avoid any wires being exposed

- It will be mounted right up to the inside wall of the main body with a carved in slot so only the active area will be exposed
- It will then be fixed using a back panel which is essentially a flat plate with extrusion on the sides to allow screwing directly into the inside wall of the body with threads for strength

We also found out that the original display panel that we found were only 3 * 3 cm which would look extremely small on the 8 * 8 side of the cube so we are planning to find a 5 * 5 cm screen to make it look more proportional

- The 5 * 5 size will also allow the mounting of the sourced camera on the side of the screen so the robot can have a visual feedback mechanism

The thickness of the walls of the main body is 4 mm as we want to keep it as thin as possible to keep as much space inside as possible while also allowing the M3 screws to be used to fix the back panel to the main body.

# Next step

- Design the back panel for the new screen and design a model for the screen if there isn’t one
- Incorporate the PCB into the design so we can use find the best place for the USB-C and buttons → the USB-C and buttons might need to be moved to be incorporated to the back panel

## Recording Links

- https://lookout.hackclub.com/api/media/2eed526c-ceec-45d9-9f8b-996a571a55fa/video.mp4

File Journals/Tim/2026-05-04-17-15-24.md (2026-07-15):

# Journal — 2026-05-04

- Author: Tim (`timwang007`)
- Source entry: 1
- Entry ID: 5456
- Created at: 2026-05-04T17:15:24Z

I was adding net names to the KiCad file based on an Excel sheet pinout that I created earlier. One problem I faced was the net DISP_MOSI is connected to the display's SDA, which is a little confusing since the display should have MOSI as well, but the datasheet calls it SDA
Screenshot 2026-05-04 at 5.31.40 PM.png

Watched a [YouTube video](https://www.youtube.com/watch?v=0nVNwozXsIc&t=15s) about SPI communication protocal

Finished all electrical connections, but got confused about the data pins on the camera since CAM_D0 should connect to Y2, not Y0. A bit surprised by the fact that cameras need three different voltages to operate. Also surprised by how I2C can allow so many slaves under one master.
current schematic.png

## Recording Links

- https://lookout.hackclub.com/api/media/140c7caa-fab2-4f09-ba3f-b6f96ad8c669/video.mp4
- https://lookout.hackclub.com/api/media/2cf7dac2-5c72-452f-add7-c756fb629be2/video.mp4
- https://lookout.hackclub.com/api/media/a6a44739-ae0b-4fc1-89b3-d4822ce151f2/video.mp4

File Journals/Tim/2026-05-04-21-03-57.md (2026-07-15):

# Journal — 2026-05-04

- Author: Tim (`timwang007`)
- Source entry: 3
- Entry ID: 5494
- Created at: 2026-05-04T21:03:57Z

- Fixed schematics with no ERC errors

Screenshot 2026-05-04 at 11.00.33 PM.png

- I don’t understand why GND pins on so many symbols are power output/ output when they are supposed to be input
- Documented parts that are not included in the BOM of the PCB in Notion for the mechanical team



- Started placing components in the PCB editor



- Asked mechanical team about the placement of headers for screen, camera, etc and the placement of the PCB itself.
- The PCB will be one layer only with components on one side, which is different than the initial thoughs about components on both side and an mother and daughter PCB. More details about old thoughts:
    - power on the daughter board, sensors and processor in top main board
    - main controllers on the top of main
    - sensors on daughter board? but need extra connector to the esp32
    - inductor on the bottom
- For context, this project started before the start of joining hackclub, so here is notes from before:

April 29, 2026 8:21 PM

# CubeOS robot design sync — mechanical, electrical, software

# Summary

Tim and Pat discussed the first concrete design direction for CubeOS: a compact cube-shaped interactive robot with screens, environmental sensors, microphone/speaker, camera, and servo-driven legs. The meeting centered on defining the product concept, narrowing mechanical assumptions, identifying electronics constraints, and creating a near-term prototype plan.

## Product Concept

- Cube-like robot form factor, initially estimated around 5 × 5 × 5 cm, potentially closer to ~7 cm once frame, screens, and mechanical clearance are included.
- Interactive remote communication device: one robot can send voice/messages to another robot, making it feel more physical and social than a phone chat.
- Potential study-buddy mode using camera presence to make remote studying feel less lonely.
- Possible movement mirroring feature: movement or gesture detected on one side could be represented on the paired robot or screen.

## Hardware / Electronics Notes

- Planned electronics include: ESP32-S3, 1.54 in TFT screens, USB-C charging/data, battery management, gyro/IMU, ambient light, IR/temperature, humidity, CO2, microphone, speaker, and camera.
- Pin budget is tight once camera and screens are included; software/electrical planning must account for ESP32-S3 GPIO limits.
- Air-exposed sensors need enclosure ventilation. Proposed solution: small holes in the frame/bottom so humidity/CO2/environment sensors can contact room air without visually large openings.
- Component sizing and datasheets are needed before finalizing frame and motor-holder geometry.

## Mechanical Notes

- Locomotion is expected to use two small servo motors, likely mounted outside or partly integrated into the lower body because there is insufficient internal cube volume.
- Main mechanical risks: leg collapse, slipping, insufficient torque, oversized motors, and awkward proportions if motors dominate the body.
- Feet likely need rubber or high-friction contact surfaces.
- Leg geometry should be prototyped before committing to full enclosure design.
- A simple flat-sheet test platform with motor holders was preferred as the fastest V1 test rig.
- MG90S-style micro servos were discussed as a likely candidate, pending final dimension/torque check.

## Software / Interaction Notes

- Core communication feature: remote message/voice transmission between paired robots.
- Later software features may include AI-mediated messages, camera-based presence/study buddy mode, sensor-based room condition reporting, and motion/gesture representation.
- Software scope is acknowledged as non-trivial and should follow after mechanical proof-of-concept and pin planning.

## Decisions

- Continue with a cube-like body rather than a non-cube form unless screen/frame constraints force a change.
- Prioritize leg mechanics as the first prototype because it is the highest-risk subsystem.
- Use a flat-sheet or simplified lower-body prototype before a complete cube enclosure.
- Use small frame ventilation holes for environmental sensors rather than a large visible opening.
- Organize the project inside the existing CubeOS Notion workspace using department pages plus the current task, roadmap, meeting-notes, and decision databases.

## Action Items

- Pat: design the first mechanical leg/motor-holder prototype, starting from a flat-sheet test rig.
- Tim / electronics owner: order or source small servo motors, screens, and related components; share exact dimensions/specs for CAD work.
- Tim / electronics owner: confirm ESP32-S3 pin allocation once camera, screens, sensors, mic/speaker, and servos are included.
- Pat + Tim: test leg angles, foot friction, rubber placement, and whether the robot tips or slips.
- Pat + Tim: document the agreed CubeOS structure and keep tasks/timelines in the existing Notion databases.

## Timeline Notes

- Immediate: collect component dimensions and start leg prototype CAD.
- Target V1 leg prototype: end of the current week or early next week, with Monday/Tuesday as the fallback target.
- Summer: remote collaboration remains possible if assembly/manufacturing happens in different places.

## Open Questions

- What exact servo model provides enough torque while fitting the desired proportions?
- Should servos be fully external, partially embedded, or hidden in a lower body/pants-like section?
- What maximum leg rotation angle works before tipping or scraping becomes unacceptable?
- How many screens are final, and how will they share SPI/control lines?
- How much of voice, AI chat, camera study-buddy, and movement sync fits into the first software milestone?

## Reference Components Mentioned / Available

- ESP32-S3 module
- 1.54 in TFT display
- Battery charger / power path management
- Ambient light sensor
- Humidity and temperature sensor
- CO2 sensor
- IR temperature sensor
- IMU / gyro
- Camera, microphone, speaker, USB-C, servos

## Recording Links

- https://lookout.hackclub.com/api/media/39be5408-feab-455c-9b3d-6322e97ee7d8/video.mp4

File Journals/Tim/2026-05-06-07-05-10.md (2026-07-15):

# Journal — 2026-05-06

- Author: Tim (`timwang007`)
- Source entry: 5
- Entry ID: 5698
- Created at: 2026-05-06T07:05:10Z

This is the first time I am doing impedance-controlled differential pairs

Used the impedance calculator from JLCPBC https://jlcpcb.com/pcb-impedance-calculator

Screenshot 2026-05-05 at 12.29.13 PM.png

The differential pair is done, but since the USB-C connector has duplicated pins to plug in both ways, it was difficult to do length matching for the DN1 DN2 and DP1 DP2.

When I was downloading 3 models from websites, Snap Magic showed me a white box when I clicked the download button and didn’t start the download. I ended up using Ultraliberian instead of Snap Magic for some of the 3d models.

I’ve decided to place the buck from the battery voltage to 3.3V on the corner of the PCB, far away from the main components like the ESP32 camera, etc., to reduce the interference from the inductor switching.

The space in front of the camera cable is left empty for easier assembly of the camera after the PCB arrives.

The differential pairs of the USB-C have their own nets and are colored in yellow to allow easy identification when routing, so that they can be prioritized first. Other high-speed signals, like the screen and camera, are colored pink for similar purposes.

Screenshot 2026-05-06 at 8.57.26 AM.png

A four-layer PCB is chosen due to the advantages of signal integrity from GND planes and easier routing on the top and bottom layers

Screenshot 2026-05-06 at 8.57.14 AM.png

4 mounting holes that are M2 are used to ensure the stability of the PCB in the cube.

Screenshot 2026-05-06 at 9.00.18 AM.png
The back screen is removed because it is not going to be used frequently, and it consumes more energy and pins on the ESP32. With the removal, one extra pin from the ESP32 is free, allowing me to add features like a button for quicker manipulation of the cube's settings without needing to go to the website to edit them.

The camera connectors have been moved a bit inwards on the PCB, since placing them on the very edge would make it difficult to connect the screen.

Removed the inner layers of copper pours under the antenna to allow the signal not to be affected by copper pours. Finally decided to cut out that part of the PCB since the “[FR4 material itself will tune the antenna to lower frequencies](https://muehlhaus.com/support/antenna/esp32-antenna-pcbsize)” The final keep out is 15mm up and 5mm down due to space constraints. The downside cannot be 15mm

Screenshot 2026-05-06 at 8.56.24 AM.png

Overview of the current PCB
Screenshot 2026-05-06 at 8.57.58 AM.png

## Recording Links

- https://lookout.hackclub.com/api/media/e6534c7e-75ba-444d-835c-9bcf73901be3/video.mp4
- https://lookout.hackclub.com/api/media/cc738978-36fe-4a84-9b9a-c6351fd547d7/video.mp4
- https://lookout.hackclub.com/api/media/199416a2-66a4-421c-b099-4867cbb06e02/video.mp4
- https://lookout.hackclub.com/api/media/060b8a9c-0e5b-4b71-8f61-1085e3f57981/video.mp4

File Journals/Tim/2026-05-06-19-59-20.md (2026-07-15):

# Journal — 2026-05-06

- Author: Tim (`timwang007`)
- Source entry: 7
- Entry ID: 5786
- Created at: 2026-05-06T19:59:20Z

While resolving the DRC errors, I found that some footprints (for example, the camera connector) had solder mask expansion set to 0.1 mm, which caused the pads to short to each other. I set the solder mask expansion to 0.05 mm to prevent pin shorting during production and to resolve the DRC errors.

Screenshot 2026-05-06 at 9.54.31 PM.png

When resolving the DRC errors, some errors indicate that the ground plane on the first layer is not connected. This is due to traces separating them, but when I clicked on the error, it only showed the whole top ground plane, not the specific pin connected to the plane, which is a little inconvenient when manually finding which pin with a GND island is not connected to the main top-layer ground plane.

Screenshot 2026-05-06 at 9.56.39 PM.png

## Recording Links

- https://lookout.hackclub.com/api/media/26697ccd-9456-4dc6-80ee-fdb7ac4f8a5f/video.mp4
- https://lookout.hackclub.com/api/media/5ca1d624-fd93-488a-98fa-69b585ae3952/video.mp4

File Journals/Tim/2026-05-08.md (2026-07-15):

# Journal — 2026-05-08

- Author: Tim (`timwang007`)
- Source entry: 10
- Entry ID: 6148
- Created at: 2026-05-08T19:48:49Z

Due to a DRC error in which the solder mask for the camera connector’s attachment pin was bridging different nets, I decided to delete the front mask polygon and draw one myself to try to resolve the issue, and it worked.
Screenshot 2026-05-08 at 12.13.25 PM.png
I had this error. My traces to the inductor are not actually in the keepout zone, but it still tells me they are not allowed. I decided to decrease the inductor’s keepout zone on both sides to resolve the DRC error, and it worked.

I decided to add a switch to turn the power on and off so that, for example, it can be switched off at night and the owner is not disturbed by the owner’s friend. There will probably be a software mode for this feature as well, but it is always nice to have a physical one that is accessible and easy to use.

A push button is also added to allow quicker control of the system’s features. While adding the push button, the footprint looked a little strange, but I managed to figure out how the switch worked.

When not pressed, 2 and 3, 6 and 5 are connected. When pressed, 1 and 2, 4 and 5 are connected.
Screenshot 2026-05-08 at 12.32.21 PM.png
This switch can be added because we previously decided to remove the back screen, which gives me one more pin on the ESP32's GPIO 5.

While trying to connect the slide switch, I realized that the footprint did not match the component because the picture showed through-hole pins, but the footprint I got only had SMD pads. I then selected a slightly different model of the switch and obtained a footprint with through-hole pads.
Screenshot 2026-05-08 at 1.35.21 PM.png
When connecting this switch, I only updated the footprint, assuming the symbol was the same. The symbol’s pin numbers were actually different, so I looked for the symbol that comes with the footprint, but it didn’t include any connection details. I then checked the datasheet and found a diagram that made it clear it behaves the same as the other switch, just with different pin numbers. I edited the current symbol to fix the issue.
Screenshot 2026-05-08 at 6.40.50 PM.png
When looking at polarity, the schematic priority is to ensure the schematics have two pins for the shell and that they are correctly labeled. The pin does not exist in your footprint because, in a footprint, pins are mechanical and therefore don’t have a pad number. Change them to through-hole so that I can match the schematics to the footprint. It is OK because most USB-C headers are so adorable.

NOOOO, my KiCad crashed, and I lost some progress.
After resolving almost all errors and warnings, I got one warning that I don’t understand. I updated my footprint multiple times, and the only change I made was to the silk screen, so there is no silkscreen cut by the edge cut due to the ESP32’s clearance.
Screenshot 2026-05-08 at 9.40.56 PM.png

## Recording Links

- https://lookout.hackclub.com/api/media/ccf44ee6-ed39-45f3-b5c0-4349fca8ac19/video.mp4
- https://lookout.hackclub.com/api/media/5e61ab34-27a6-44ea-8688-33f72ee83180/video.mp4
- https://lookout.hackclub.com/api/media/da6dc8c5-6569-4860-857f-fd774d5d2697/video.mp4

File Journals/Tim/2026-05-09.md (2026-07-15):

# Journal — 2026-05-09

- Author: Tim (`timwang007`)
- Source entry: 12
- Entry ID: 6334
- Created at: 2026-05-09T21:26:00Z

I finished my PCB, including all the Gerber files, materials, and component placement files. But then, while ordering, I realized that JOCPC doesn’t have that component, so I had to change it. I switched to the same category of component but with a different footprint. That footprint has very small pads, so I always run into clearance issues when I try to route that component on the PCB, even after changing the solder mask and copper pad settings. I still couldn’t get it to work, so now I’m trying to find a component that doesn’t have the same issue—not from Texas Instruments, but from another company.

Screenshot 2026-05-09 at 11.19.09 PM.png

Texas Instruments
TPS7A0228DQNR

Side pins too small to route with clearance constraints
NOOOO, my Kicad crashed

The component is switched to LDLN025M25R, which is for converting 3.3V to 2.8V for the camera

The first version with SMT assembly of 2 PCB boards out of 5 is very expensive, nearly 200 dollars, mainly due to the expensive sensors. I will try to switch to cheaper versions or remove redundant sensors if applicable

Screenshot 2026-05-09 at 8.44.24 PM.png

When placing components on the JLCPCB editor for SMT, I thought the screen connectors were the wrong way around since the moving piece was facing the inside, but after checking the datasheet, it turned out to be correct.
Screenshot 2026-05-09 at 11.18.01 PM.png

## Recording Links

- https://lookout.hackclub.com/api/media/a0925c29-8157-4e34-90d1-569a5045d69d/video.mp4
- https://lookout.hackclub.com/api/media/91a749dd-8fd3-47dd-8448-923242b1e4d5/video.mp4

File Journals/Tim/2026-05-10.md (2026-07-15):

# Journal — 2026-05-10

- Author: Tim (`timwang007`)
- Source entry: 14
- Entry ID: 6496
- Created at: 2026-05-10T21:13:39Z

Removed MLX90632SLD-DCB-000-RE
Removed SCD41-D-R2

The first is a CO2 sensor, and the second is a long-wavelength sensor. They could provide additional features like an air quality tracker that sits on your desk, but due to the expensive components and the primary function of connecting friends from long distances, these sensors are omitted to ensure affordability.

After removing these components, the PCB cost with production cost is 144 dollars per 2 boards with SMT assembly, so around 70 dollars per robot.

Screenshot 2026-05-10 at 10.13.29 PM.png

Other time is spent on burnout messages, including updating documentation, compiling BOM, and compiling past projects

Also discussed with teammates about the features the PCB allows

Added stitching vias using an open-source KiCad plugin
Screenshot 2026-05-10 at 11.03.41 PM.png

Added 3d models
Screenshot 2026-05-10 at 11.11.51 PM.png

## Recording Links

- https://lookout.hackclub.com/api/media/4a5dadd8-9b22-47ea-a9c1-a276a522be1b/video.mp4
- https://lookout.hackclub.com/api/media/22e9e23b-9da8-4008-85b4-c0189affdee2/video.mp4

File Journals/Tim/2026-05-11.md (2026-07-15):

# Journal — 2026-05-11

- Author: Tim (`timwang007`)
- Source entry: 16
- Entry ID: 6658
- Created at: 2026-05-11T20:24:47Z

Used the codex with the datasheet to look through my KiCad file to find any errors

Screenshot 2026-05-11 at 4.07.46 PM.png

VSS pins are changed to GND

The ESP32 model has changed. N8R8 to N8R2 so that these pins can be kept:

CAM_D0 = GPIO35
CAM_D1 = GPIO36
CAM_D2 = GPIO37

R6 is changed from 2.4k ohms to 3.6k ohms

each display’s LEDA is connected to a 10 ohms resistor in series to limit current

AVDD, DOVDD, and DVDD have a 0.1 uF cap

The linear regulator is changed from output of 2.5V to 2.8V with LDLN025J28R for AVDD

Discussed with the mechanical team, where all the connectors that have connections towards the outside have to be concentrated on one side of the PCB because the cube itself will be bigger than the PCB side, if placed on a different side, some connectors like USB-C or buttons cannot be reached.

Planning to use the GPIO extension chip to gain more GPIOs from my ESP32 chip, model is Texas Instruments TCA6408A

## Recording Links

- https://lookout.hackclub.com/api/media/a798fe4d-ff3e-4db1-be8d-4e0ade5f77f6/video.mp4

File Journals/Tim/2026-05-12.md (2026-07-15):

# Journal — 2026-05-12

- Author: Tim (`timwang007`)
- Source entry: 17
- Entry ID: 6788
- Created at: 2026-05-12T16:08:52Z

Connections of the ESP32 are changed due to the risk of connecting something to the strapping pins, which are GPIO0, GPIO3, GPIO45, and GPIO46. 
Screenshot 2026-05-12 at 6.03.27 PM.png
Moved connectors to the same side of the USB-C connector and reconnected traces for the pin changes. 0 warnings and errors in DRC
Screenshot 2026-05-12 at 6.04.31 PM.png
Current status
Screenshot 2026-05-12 at 6.05.04 PM.png
The resistor in front of the connector might be a problem though

## Recording Links

- https://lookout.hackclub.com/api/media/ab153748-ae4a-4c54-af7a-8187dfcd1573/video.mp4

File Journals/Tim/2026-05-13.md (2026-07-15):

# Journal — 2026-05-13

- Author: Tim (`timwang007`)
- Source entry: 18
- Entry ID: 6937
- Created at: 2026-05-13T15:32:00Z

Added test points for these nets:

GND, USB_VBUS, BAT_IN, ESP32_EN, Buck_IN, Buck_OUT_3.3V, ESP32_BOOST, I2C_SDA, I2C_SCL, CHG_PGOOD, CHG_STAT, DISP_SCLK, DISP_MOSI, DISP_BL_PWM

The screen cable connector 3d model is oriented the wrong way, so I have now fixed it

Moved the resistors that were in front of the screen connector to the side of the connector so that they don't interfere with the screen cable

Added all 3d models except the switches because they are not available online

Added 4.7uF to 47uF from BAT to GND for BQ24074 to allow current surges, also recommended by the data sheet.

Changed input caps for camera power to 1uf instead of 0.1uF to ensure there is enough capacitance for the camera’s current draw

I will ask Codex to check my PCB again so that any errors can be eliminated before production

Current status:
Screenshot 2026-05-13 at 5.27.41 PM.png

## Recording Links

- https://lookout.hackclub.com/api/media/2ece1bf4-3e2c-4e93-8e67-0bed4dec24a7/video.mp4

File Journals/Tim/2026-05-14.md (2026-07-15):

# Journal — 2026-05-14

- Author: Tim (`timwang007`)
- Source entry: 20
- Entry ID: 7130
- Created at: 2026-05-14T16:47:18Z

I increased the width of the main 3.3V trace from 0.2mm to 0.4mm to handle potentially 0.5A of current draw from all the electronics
Screenshot 2026-05-14 at 6.15.47 PM.png
Added a pull-down resistor for the mic data line as recommended in the data sheet
Screenshot 2026-05-14 at 6.15.30 PM.png
The mechanical team and I decided to switch screens because the current selected screen is a bit too small for the robot. We have a free option that ranges from 2.4 to 2.8 and 3.2-inch displays, but we haven’t decided which one to use
The new screens have Molex 503480-1200 connectors

## Recording Links

- https://lookout.hackclub.com/api/media/125c0558-eb2e-4dfb-bbb2-b8819cf3e2d1/video.mp4

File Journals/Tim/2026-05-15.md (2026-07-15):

# Journal — 2026-05-15

- Author: Tim (`timwang007`)
- Source entry: 22
- Entry ID: 7281
- Created at: 2026-05-15T16:46:49Z

The mechanical team and I decided to use the [2.4-inch screen](https://ronboelectronics.en.made-in-china.com/product/pFOaqvkHkWci/China-2-4-Inch-Resolution-Qvga-240X320-12pin-Spi-FPC-Zif-Connector-Type-IPS-LCD-Displays.html) for our new screen since it is much bigger than the previous one

So I changed the symbol and footprint in Kicad to suit the screen, but while I was retracing the connections, after tracing 3 out of 4 connectors, I realized I had to rotate connector 180° so that the opening side faces outward, which is the opposite of the last connector. 

When tracing, I also realized that we will probably need an extender for the screen cables, since the default cables that come with the screen are pretty short, and the PCB won’t be in the center anyway. It looks something like this:

Screenshot 2026-05-15 at 6.44.11 PM.png

https://de.aliexpress.com/item/33020782574.html?gatewayAdapt=glo2deu

## Recording Links

- https://lookout.hackclub.com/api/media/f53a7107-c443-474c-a055-4be83cc58389/video.mp4

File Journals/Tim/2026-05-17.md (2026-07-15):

# Journal — 2026-05-17

- Author: Tim (`timwang007`)
- Source entry: 23
- Entry ID: 7638
- Created at: 2026-05-17T16:38:32Z

Fixed pull-up for the PGOOD and charge status of the charging controller.

Reconnected all connections for the new display connector and added 3d models

Added pull-down resistor for the I2S_MIC_DATA line

Switched the on/off switch between the charger chip and the buck, to the EN pin of the buck converter’s chip, to make sure that it can be charged even when the switch is turned off

Changed the NTC thermistor’s position to somewhere close to the battery connector so it can actually measure battery temperature
Screenshot 2026-05-17 at 5.57.16 PM.png
Switched the battery’s pin connections to the correct orientation as the diagram provided by the battery manufacturer.
Screenshot 2026-05-17 at 5.58.22 PM.png
Added switches to the GPIO 0 and EN of the ESP for manual boot and reset.
Screenshot 2026-05-17 at 6.29.14 PM.png

## Recording Links

- https://lookout.hackclub.com/api/media/516b0497-60b9-456e-ad13-24d01835de65/video.mp4

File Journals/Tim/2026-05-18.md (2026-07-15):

# Journal — 2026-05-18

- Author: Tim (`timwang007`)
- Source entry: 24
- Entry ID: 7799
- Created at: 2026-05-18T15:50:39Z

Switched from TCA6408ARSVR to TCA6408ARGTR due to the lack of stock of TCA6408ARSVR in JLCPCB’s inventory

Added stitching vias using a Kicad plugin.

Exported Gerber and production files. Finished putting the PCB board into JLCPCB
Screenshot 2026-05-17 at 8.33.11 PM.png
Used PlatformIO + VS Code to connect to an ESP32 by Berrybase that has an ESP-WROOM-32 chip to start doing the firmware part before the PCB arrives. Used the WIFI_AP mode to make the ESP32 an access point and host a test wifi to verify if the ESP32 is working properly or not.

Created a form using HTML to allow the user to input their home Wi-Fi credentials

Switched to WIFI_AP_STA to allow ESP32 to connect while hosting the wifi

While testing the ESP32, after the initial upload, the ESP32 will keep resetting, and the reason is Reset reason: 1”, which is a power dip; it might be a bad cable or settings in the pio.ini file. I dont think it is a setting error since ESP-WROOM-32 is usally “board = esp32dev”, bad cable or connector to my computer could be the problem but i dont have any other cable currently so I will try to trouble shoot this once I have anther cable.

Added a Wi-Fi connection route with a timeout mechanism

Tried to connect to my phone’s hotspot, and it worked

I switched cables, and the initial upload still has weird text and continuous reboot, but after a certain amount, it stops and becomes normal and sets up the server
Screenshot 2026-05-18 at 5.33.07 PM.png
After the ESP32 is connected to wifi and the user’s device is on the same wifi, I used mDNS to enable the user to access the local host of the dashboard of the CubeOS
Screenshot 2026-05-18 at 5.33.55 PM.png

## Recording Links

- https://lookout.hackclub.com/api/media/cb6ac8a4-79fe-44b3-8a47-a95e3fcf4d37/video.mp4
- https://lookout.hackclub.com/api/media/2faa25ae-9673-4b7b-9891-cff4c8527669/video.mp4

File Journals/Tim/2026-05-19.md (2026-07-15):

# Journal — 2026-05-19

- Author: Tim (`timwang007`)
- Source entry: 25
- Entry ID: 8019
- Created at: 2026-05-19T18:53:47Z

Started organizing code structures using .h files and separate .cpp files to separate code like movement or setup.
Screenshot 2026-05-19 at 8.35.25 PM.png
Also set up config.h for pins on the CubeOS to keep everything clean
The config.h file is updated with the current connections in Rev A
Screenshot 2026-05-19 at 8.36.20 PM.png
Created a simple test code for movement, also added this structure commented for further testing after basic testing succeeds:
ISM330DHCX library  ->  complementary filter  ->  walking correction
Here are the types of communication between different CubeOSs.

WebSocket:

- remote drive commands
- live robot state
- camera JPEG frames, at least for first version

HTTP POST:

- voice message uploads
- short video/photo uploads
- logs or crash reports

MQTT:

- excellent for online/offline, telemetry, command topics

## Recording Links

- https://lookout.hackclub.com/api/media/e4f1bf13-b215-4661-aa2d-10335fddc703/video.mp4
- https://lookout.hackclub.com/api/media/3c3b0659-9904-486e-93e2-31a76cab3b4c/video.mp4

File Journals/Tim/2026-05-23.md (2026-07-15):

# Journal — 2026-05-23

- Author: Tim (`timwang007`)
- Source entry: 26
- Entry ID: 8625
- Created at: 2026-05-23T09:40:57Z

Software basics
* #include <> includes a library that contains objects, functions, constants, or even other liberary, etc that is written by someone else
* Function: a set of codes that was written by someone else and can be easily implemented by others, like void setup() {}, which is in the Arduino library
* A void in front of a function means the function doesn't return a value; it returns void, which is nothing. It can be used when I want to turn a LED on and I can see the LED on so I dont need something to be returned from the function
* namespace, like NameOfSpace {, creates something like a folder in the code itself, which allows functions that have the same name to be called and can shorten function names when code becomes complicated, such as Camera::start();, which calls the start function in the Camera namespace
* Objects have blueprints and the object itself. Blueprints are created using this: class Robot. Objects are created using Robot cube1;. 
    * Objects can store states like cube1.battery = 90; when running cube1.battery, it will return 90
    * Objects are often under namespaces since namespaces give the overall structure of the code, and objects store actual values and functions which can be called by NameSpace::Blueprint Object;
    * Objects have access specifiers, such as public, private, and protected.
    * A good example is Serial.begin(SERIAL_BAUD_RATE);, where the Serial is a object and begin() is a function inside the object. the Serial object is included in the Arduino liberary
* Types define the type of data that the variable stores or the function returns, such as int, float, string, etc
* const makes a variable unchangeable after it is defined. const int age = 17; you cannot do age = 18 since it has a const when defined
* A compiler turns commands from the programming language as a whole, such as C++, into machine code that can be run by the CPU or microcontroller. The compiler compiles the whole machine code during build time
* An interpreter runs commands line by line and moves to the next line after the last one, unlike a compiler. Examples of languages using an interpreter are Python. An interpreter interprets the code line by line at run time
Screenshot 2026-05-23 at 11.40.32 AM.png

## Recording Links

- https://lookout.hackclub.com/api/media/e0f1bd40-17fc-4d5f-8728-dae2bc121c24/video.mp4

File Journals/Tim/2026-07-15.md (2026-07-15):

# Journal — 2026-07-15

- Author: Tim (`timwang007`)
- Created at: 2026-07-15

Started testing the Rev A PCB because my Mac could not detect the ESP32-S3 when I connected the USB-C cable. At first I thought the ESP32 or the cable might have a problem, so I started measuring the test points to find where the power stopped.

The first measurements were:

- TP2 was around 5V, so USB power was reaching the PCB
- TP5 was around 4.47V
- TP6 and TP4 were 0V
- TP6, TP10, and TP11 stayed at 0V in both switch positions
- TP5 did not change when I moved the switch

This meant the BQ24074 power path was working up to TP5, but the TPS63802 was not producing the 3.3V rail for the ESP32.

I measured the switch pins and found that the outside pin was always around 4.47V while the inside pin was always 0V. Using continuity mode, I realized that the installed switch did not connect the middle pads in the way the schematic expected. In one position, pads 1, 4, and 5 were connected together.

In the schematic, pad 5 is connected to the TPS63802 input and pad 2 is connected to its EN pin. Because the real switch contacts did not connect pads 5 and 2, moving the switch never enabled the regulator. I soldered a jumper between pads 1 and 2, so when the switch connects pad 5 to pad 1, the voltage also reaches pad 2 and enables the TPS63802.

After adding the jumper, macOS finally showed this message:

```text
Allow accessory to connect?
Espressif USB JTAG/serial debug unit
```

The ESP32 also appeared as a port similar to:

```text
/dev/cu.usbmodem101
VID:PID = 303A:1001
Description = USB JTAG/serial debug unit
```

This confirmed that the ESP32 had power and that the UGREEN USB-C cable could carry both power and data.

I also changed the PlatformIO configuration from the generic ESP32 target to the ESP32-S3 target:

```ini
[env:cubeos-reva]
platform = espressif32
board = rymcu-esp32-s3-devkitc-1
framework = arduino

build_flags =
  -DARDUINO_USB_CDC_ON_BOOT=1

lib_deps =
  adafruit/Adafruit LSM6DS
  adafruit/Adafruit BusIO
  adafruit/Adafruit Unified Sensor

monitor_speed = 115200
monitor_rts = 0
monitor_dtr = 0
upload_speed = 115200
```

`ARDUINO_USB_CDC_ON_BOOT` enables serial over the ESP32-S3 native USB connection. I also learned that RTS and DTR are old serial control signals that ESP boards can reuse to control reset and boot mode. Setting both monitor values to 0 prevents the monitor from intentionally holding those signals active.

The first recovery upload used:

```bash
cd "/Users/a1/Desktop/Cube OS/Firmware"
pio run -e cubeos-reva --target clean
pio run -e cubeos-reva --target upload --upload-port /dev/cu.usbmodem101
```

I also used the BOOT and RESET buttons for the first recovery upload. Before this, the ESP32 printed `invalid header: 0xffffffff`, which meant it was reading erased flash instead of a valid firmware image. Cleaning removed the previously compiled files after changing the board target, but the main fix was getting the power working, entering download mode, and writing a complete valid image. Later uploads started working automatically without pressing the buttons.

After uploading, I found another issue in the device monitor:

```text
ledcSetup(): No more LEDC channels available! (maximum 8) or bit width too big (maximum 14)
LEDC is not initialized
```

The servo PWM code used 16-bit resolution, but this ESP32-S3 Arduino setup only supports up to 14 bits. I changed:

```cpp
constexpr int SERVO_PWM_RESOLUTION_BITS = 16;
```

to:

```cpp
constexpr int SERVO_PWM_RESOLUTION_BITS = 14;
```

The monitor also printed `nvs_open failed: NOT_FOUND`. This was not the reset problem. It only meant that the fresh ESP32 did not have saved Wi-Fi credentials yet, so the firmware correctly started setup mode.

The firmware reached:

```text
Setup access point started
Network name: CubeOS-Setup
Setup URL: http://192.168.4.1
Web server started
```

Then the USB device disappeared and the ESP32 rebooted. I also tried uploading without opening Device Monitor, but the `CubeOS-Setup` network still did not stay visible. This made it less likely that the monitor itself was causing the reset.

At first I thought the Wi-Fi current spike might be causing a power problem, so I used a FNIRSI DSO-510 oscilloscope. I used X10 on both the probe and scope, DC coupling, 1V/div, 10ms/div, Single trigger mode, and a falling-edge trigger. The scope only has one channel, so I repeated the startup separately for each test point.

The scope results were:

- TP6 dropped from around 3.3V to around 2V
- TP5 dropped from around 4.47V to around 3.32V
- TP2 did not cross the 4.72V falling trigger threshold

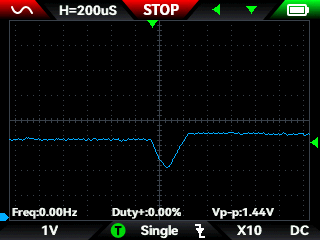
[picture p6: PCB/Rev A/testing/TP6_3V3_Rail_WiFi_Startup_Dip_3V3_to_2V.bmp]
TP6 3.3V rail Wi-Fi startup dip


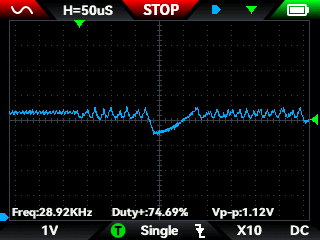
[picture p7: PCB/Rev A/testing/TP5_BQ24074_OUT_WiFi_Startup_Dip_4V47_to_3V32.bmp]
TP5 BQ24074 output Wi-Fi startup dip


The TP6 measurement finally confirmed that this is a real power reset. Around 2V is far below what the ESP32-S3 needs, which explains why USB disconnects and the setup network disappears.

Since TP5 also drops but TP2 stays above 4.72V, the collapse starts inside the BQ24074 power-path section instead of at the Mac or USB cable. The switch jumper only carries the TPS63802 enable signal, not the regulator load current, so the jumper is probably not causing the TP5 voltage drop.

I measured R5 with the board disconnected and got 3.3kΩ, which matches the BOM. R5 connects to ILIM and controls the BQ24074 USB input-current limit. For this resistor range, the typical limit is around:

```text
1525 / 3300 = 0.462A
```

R6 is separate and controls battery-charging current. The ILIM setting applies to the total input current used by the system and battery charging. During all these measurements, I had no battery, servos, screens, camera, or other external parts connected. A possible explanation is that the ESP32 Wi-Fi startup reaches the input limit, and there is no battery attached to supplement the short current spike.

I checked whether the Mac could show the board's real current draw, but macOS only reports USB device or requested-power information, not a useful live measurement of a short transient. I would need an inline USB-C power meter or a bench supply with current measurement to see the actual peak.

The next test is to connect a correct 1S 3.7V LiPo battery and see whether it keeps TP6 at 3.3V when Wi-Fi starts. The battery connector on the PCB is JST-PH with two pins and 2mm pitch:

- J1 pin 1 is GND and connects to TP1
- J1 pin 2 is battery positive and connects to TP3
- The mating housing is PHR-2

My battery has a different connector, so I am going to make an adapter instead of soldering directly to the battery or PCB. I will use around 0.1m of 26AWG wire, which is inside the JST-PH contact's supported wire range. Before connecting it, I need to verify the polarity with a multimeter because battery connectors can use the same housing with the red and black wires reversed.

If TP6 stays near 3.3V and `CubeOS-Setup` remains visible with the battery connected, it will confirm that the no-battery/current-limit condition caused the reset. If TP6 still collapses, I will need to investigate the BQ24074 soldering and control pins, the TPS63802, or an unexpectedly large load somewhere on the PCB.

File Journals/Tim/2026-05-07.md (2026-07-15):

# Journal — 2026-05-07

- Author: Tim (`timwang007`)
- Source entry: 8
- Entry ID: 5920
- Created at: 2026-05-07T16:36:49Z

I was trying to make an AI workflow for one of the features in the Cube OS robot. I first tried using a platform called Flowise. It worked, but I felt like I did not have enough control over the workflow, so I switched to n8n and downloaded it through a Docker image.
Screenshot 2026-05-07 at 6.33.59 PM.png

Screenshot 2026-05-07 at 6.34.07 PM.png

In n8n, I wanted to set up two ChatGPT agents. One agent would argue against an idea, and the other would argue for it. However, the workflow ended up running twice, which was not ideal. Because of that, I started testing different methods, such as using split nodes, merge nodes, and changing key names.

At first, renaming the keys worked well. I gave the first output one name and the second output a different name, so the third ChatGPT agent could recognize them as two separate pieces of text. Without changing the key names, both outputs had the same name, so the third ChatGPT agent would treat them as the same input.

However, I felt that changing the key names was a little sketchy, so I kept looking for a better method. I tried using different nodes to combine the outputs into one larger list or into lists with different names. My goal was for the third ChatGPT agent to clearly recognize the two different outputs.

After multiple trials, I ended up using a merge node with the mode set to “combine.” I used “combine by position” with two inputs from the two ChatGPT agents. For clash handling, I selected the option to always add the input number to field names when field values clash. This allowed the two outputs to merge into one larger list while still keeping their field names different.

Screenshot 2026-05-07 at 6.32.28 PM.png
This method worked because the third ChatGPT agent could now receive and identify both outputs separately. It could use one response from the agent arguing for the idea and another response from the agent arguing against it.

Screenshot 2026-05-07 at 6.33.09 PM.png

Screenshot 2026-05-07 at 6.31.50 PM.png
I also ran into another issue when setting up the ChatGPT node. When I tried to select a model from the list, n8n did not clearly recognize the error. After searching it up, I think this was an n8n issue. To fix it, I used the model ID instead of selecting from the list, and then it worked.
Screenshot 2026-05-07 at 6.32.03 PM.png

## Recording Links

- https://lookout.hackclub.com/api/media/ce41a51b-0725-4629-aa58-efc2e4a38c34/video.mp4

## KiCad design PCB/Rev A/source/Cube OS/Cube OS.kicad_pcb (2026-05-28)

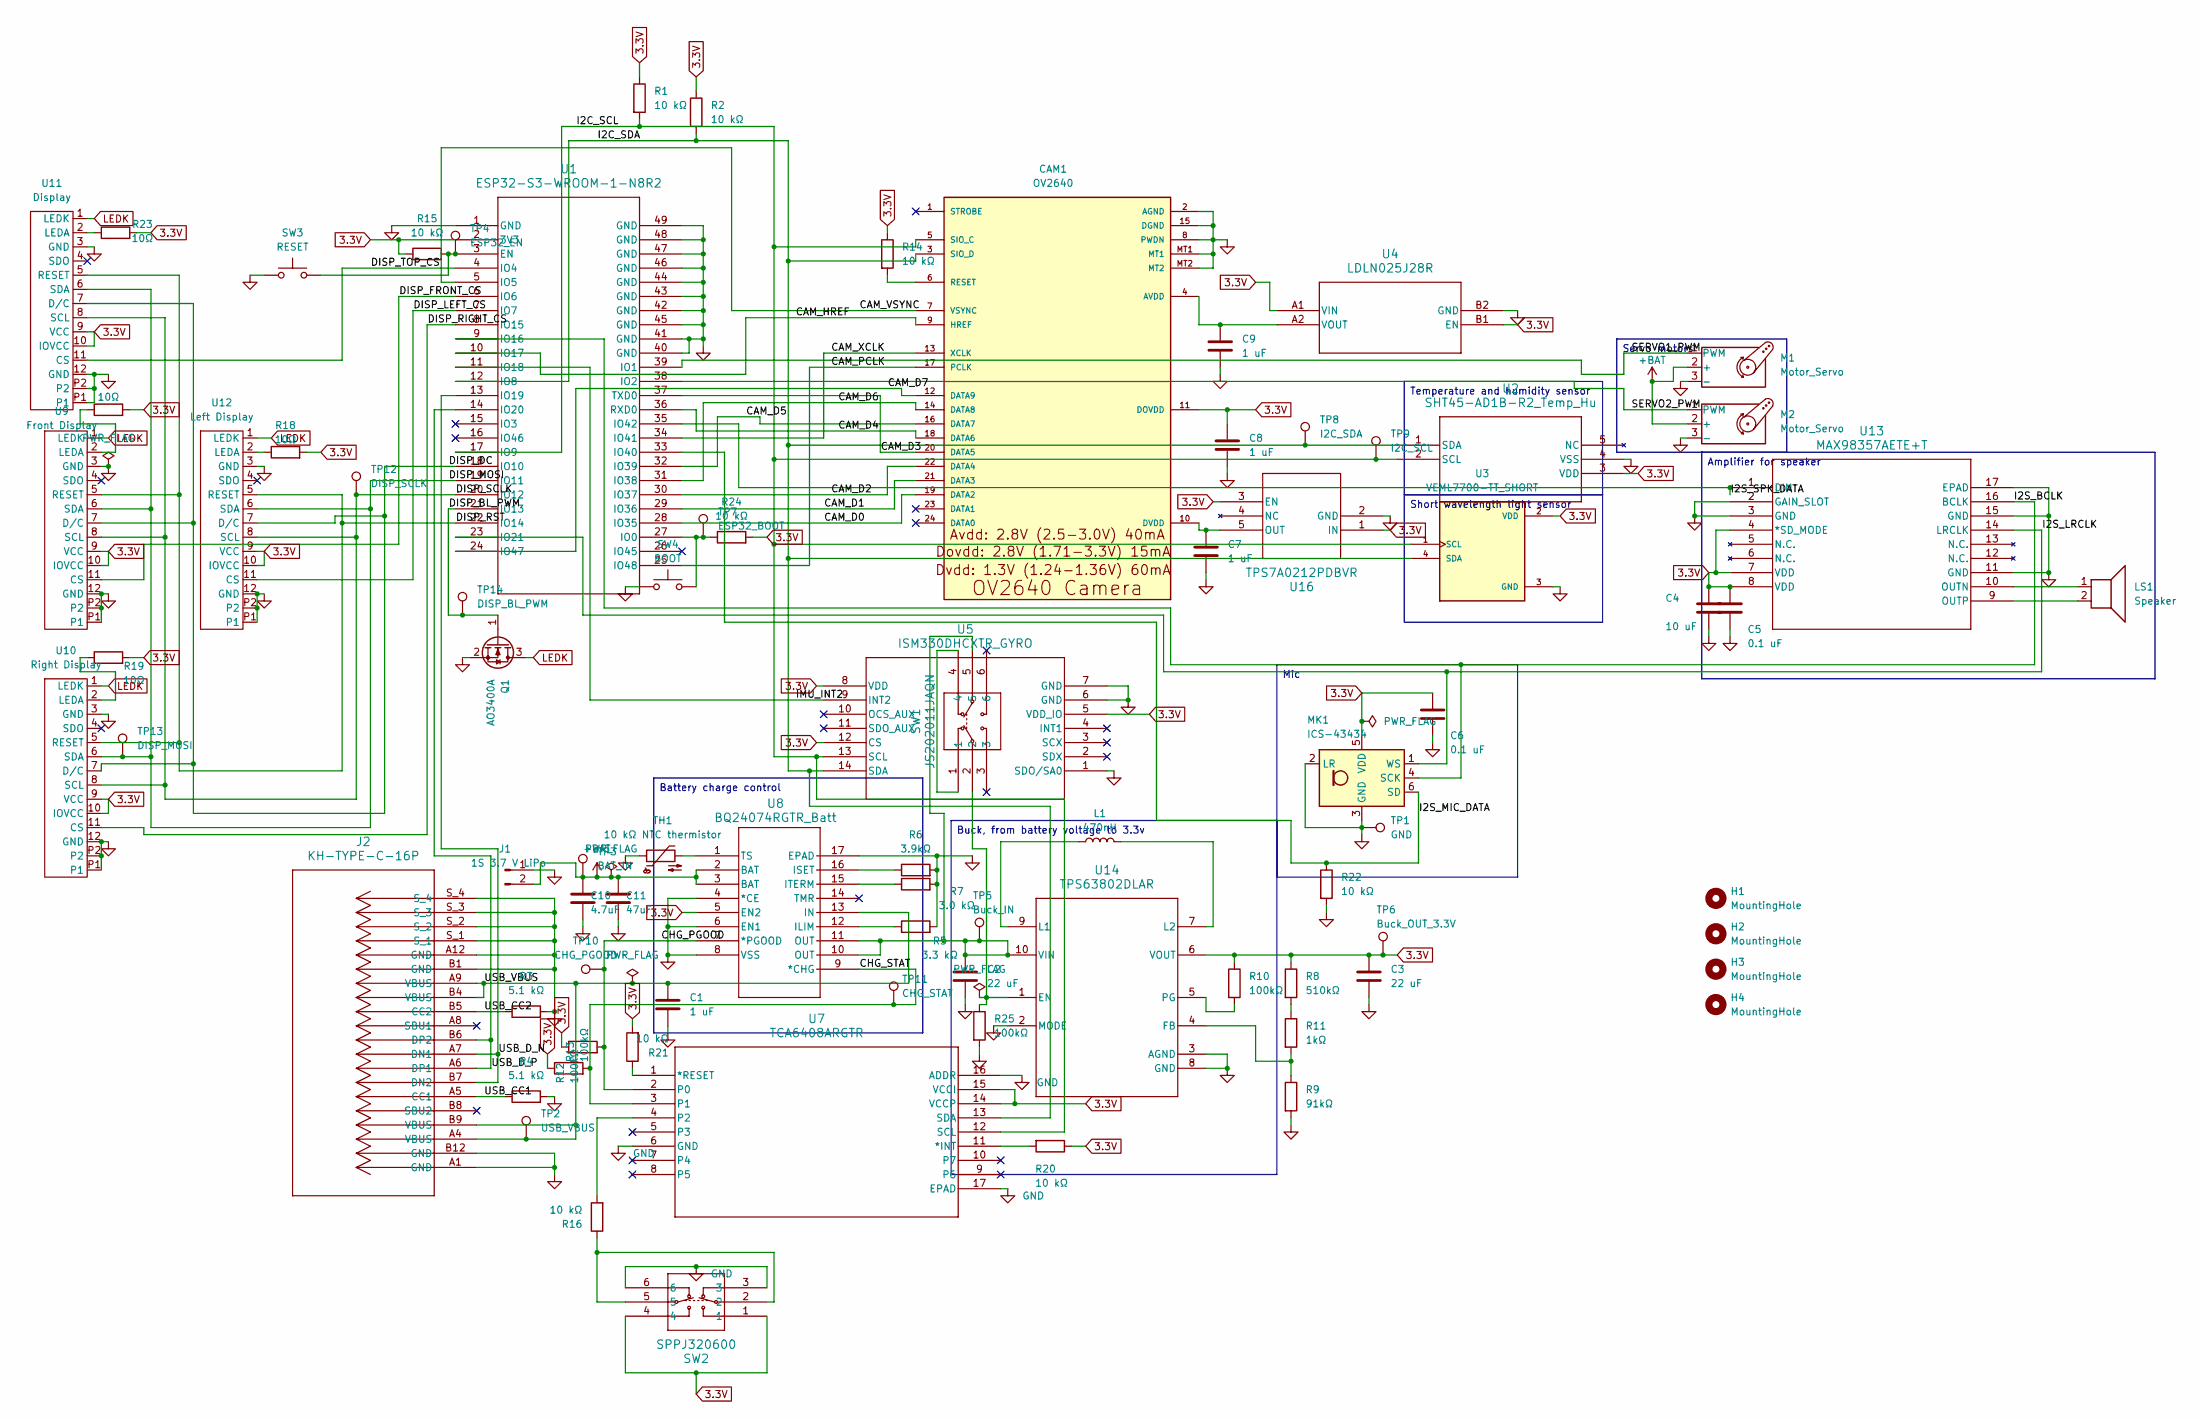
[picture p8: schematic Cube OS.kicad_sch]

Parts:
C1, C7, C8, C9: 1 uF; C_0402_1005Metric; JLCPCB C52923
C2, C3: 22 uF; C_0603_1608Metric; JLCPCB C59461
C4: 10 uF; C_0402_1005Metric; JLCPCB C15525
C5, C6: 0.1 uF; C_0402_1005Metric; JLCPCB C1525
C10: 4.7uF; C_0402_1005Metric; JLCPCB C23733
C11: 47uF; C_0805_2012Metric; JLCPCB C16780
CAM1: OV2640; AMPHENOL_F32R-1A7H1-11024; JLCPCB C3167938
H1, H2, H3, H4: MountingHole; MountingHole_2.2mm_M2
J1: 1S 3.7 V LiPo; JST_PH_B2B-PH-K_1x02_P2.00mm_Vertical; JLCPCB C131337
J2: KH-TYPE-C-16P; CONN_KH-TYPE-C_SKE; JLCPCB C709357
L1: 470nH; IND_MWSA0603S_SNL; JLCPCB C408439
LS1: Speaker; JST_PH_B2B-PH-K_1x02_P2.00mm_Vertical; JLCPCB C131337
M1, M2: Motor_Servo; PinHeader_1x03_P2.54mm_Vertical; JLCPCB C49257
MK1: ICS-43434; InvenSense_ICS-43434-6_3.5x2.65mm; JLCPCB C5656610
Q1: AO3400A; SOT-23; JLCPCB C20917
R1, R2, R14, R15, R16, R20, R21, R22, R24: 10 kΩ; R_0402_1005Metric; JLCPCB C25744
R3, R4: 5.1 kΩ; R_0402_1005Metric; JLCPCB C25905
R5: 3.3 kΩ; R_0402_1005Metric; JLCPCB C25890
R6: 3.9kΩ; R_0603_1608Metric; JLCPCB C23018
R7: 3.0 kΩ; R_0603_1608Metric; JLCPCB C4211
R8: 510kΩ; R_0603_1608Metric; JLCPCB C23192
R9: 91kΩ; R_0603_1608Metric; JLCPCB C23265
R10, R12, R13, R25: 100kΩ; R_0402_1005Metric; JLCPCB C25741
R11: 1kΩ; R_0402_1005Metric; JLCPCB C11702
R17, R18, R19, R23: 10Ω; R_0603_1608Metric; JLCPCB C22859
SW1: JS202011JAQN; SWITCH_011CQN; JLCPCB C221662
SW2: SPPJ320600; SPPJ320600_AAL; JLCPCB C470431
SW3: RESET; SW_TS-1088_XNP; JLCPCB C720477
SW4: BOOT; SW_TS-1088_XNP; JLCPCB C720477
TH1: 10 kΩ NTC thermistor; R_0402_1005Metric; JLCPCB C77131
TP1: GND; TestPoint_Pad_1.0x1.0mm
TP2: USB_VBUS; TestPoint_Pad_1.0x1.0mm
TP3: BAT_IN; TestPoint_Pad_1.0x1.0mm
TP4: ESP32_EN; TestPoint_Pad_1.0x1.0mm
TP5: Buck_IN; TestPoint_Pad_1.0x1.0mm
TP6: Buck_OUT_3.3V; TestPoint_Pad_1.0x1.0mm
TP7: ESP32_BOOT; TestPoint_Pad_1.0x1.0mm
TP8: I2C_SDA; TestPoint_Pad_1.0x1.0mm
TP9: I2C_SCL; TestPoint_Pad_1.0x1.0mm
TP10: CHG_PGOOD; TestPoint_Pad_1.0x1.0mm
TP11: CHG_STAT; TestPoint_Pad_1.0x1.0mm
TP12: DISP_SCLK; TestPoint_Pad_1.0x1.0mm
TP13: DISP_MOSI; TestPoint_Pad_1.0x1.0mm
TP14: DISP_BL_PWM; TestPoint_Pad_1.0x1.0mm
U1: ESP32-S3-WROOM-1-N8R2; ESP32-S3-WROOM-1_EXP; JLCPCB C2913204
U2: SHT45-AD1B-R2_Temp_Hu; SHT4x_SEN; JLCPCB C5221601
U3: VEML7700-TT_SHORT; XDCR_VEML7700-TT; PARTREV 1.6; DigiKey_Part_Number 751-VEML7700-TTCT-ND
U4: LDLN025J28R; FLIPCHIP4_0P658X0P658_STM; JLCPCB C2971613
U5: ISM330DHCXTR_GYRO; LGA-14L_STM; JLCPCB C2655101
U7: TCA6408ARGTR; RGT16_1P45X1P45; JLCPCB C181499
U8: BQ24074RGTR_Batt; RGT16_1P7X1P7; JLCPCB C54313
U9: Front Display; CON_5034801200_MOL; JLCPCB C587969
U10: Right Display; CON_5034801200_MOL; JLCPCB C587969
U11: Display; CON_5034801200_MOL; JLCPCB C587969
U12: Left Display; CON_5034801200_MOL; JLCPCB C587969
U13: MAX98357AETE+T; 21-0136I_T1633-4_MXM; JLCPCB C910544
U14: TPS63802DLAR; DLA0010A; JLCPCB C2845237
U16: TPS7A0212PDBVR; SOT23_DBV_TEX; JLCPCB C5220172

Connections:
3.3V: C3.1, C4.1, C5.1, C6.1, C8.1, CAM1.11 (DOVDD), MK1.5 (VDD), R1.1, R2.1, R8.1, R10.1, R12.1, R13.1, R14.1, R15.1, R17.2, R18.2, R19.2, R20.1, R21.2, R23.2, R24.2, SW2.1, SW2.4, TP6.1, U1.2 (3V3), U2.3 (VDD), U3.2 (VDD), U4.A1 (VIN), U4.B1 (EN), U5.5 (VDD_IO), U5.8 (VDD), U5.12 (CS), U7.14 (VCCP), U7.15 (VCCI), U8.5 (EN2), U9.9 (VCC), U9.10 (IOVCC), U10.9 (VCC), U10.10 (IOVCC), U11.9 (VCC), U11.10 (IOVCC), U12.9 (VCC), U12.10 (IOVCC), U13.4 (*SD_MODE), U13.7 (VDD), U13.8 (VDD), U14.6 (VOUT), U16.1 (IN), U16.3 (EN)
+BAT: C10.1, C11.1, J1.2, M1.2 (+), M2.2 (+), TP3.1, U8.2 (BAT), U8.3 (BAT)
/CAM_D0: CAM1.19 (DATA2), U1.28 (IO35)
/CAM_D1: CAM1.21 (DATA3), U1.29 (IO36)
/CAM_D2: CAM1.22 (DATA4), U1.30 (IO37)
/CAM_D3: CAM1.20 (DATA5), U1.37 (TXD0)
/CAM_D4: CAM1.18 (DATA6), U1.36 (RXD0)
/CAM_D5: CAM1.16 (DATA7), U1.32 (IO39)
/CAM_D6: CAM1.14 (DATA8), U1.31 (IO38)
/CAM_D7: CAM1.12 (DATA9), U1.24 (IO47)
/CAM_HREF: CAM1.9 (HREF), U1.10 (IO17)
/CAM_PCLK: CAM1.17 (PCLK), U1.25 (IO48)
/CAM_VSYNC: CAM1.7 (VSYNC), U1.5 (IO5)
/CAM_XCLK: CAM1.13 (XCLK), U1.34 (IO41)
/CHG_PGOOD: R13.2, TP10.1, U7.2 (P0), U8.7 (*PGOOD)
/CHG_STAT: R12.2, TP11.1, U7.3 (P1), U8.9 (*CHG)
/DISP_BL_PWM: Q1.1 (G), TP14.1, U1.21 (IO13)
/DISP_DC: U1.18 (IO10), U9.7 (D/C), U10.7 (D/C), U11.7 (D/C), U12.7 (D/C)
/DISP_FRONT_CS: U1.6 (IO6), U9.11 (CS)
/DISP_LEFT_CS: U1.7 (IO7), U12.11 (CS)
/DISP_MOSI: TP13.1, U1.19 (IO11), U9.6 (SDA), U10.6 (SDA), U11.6 (SDA), U12.6 (SDA)
/DISP_RIGHT_CS: U1.8 (IO15), U10.11 (CS)
/DISP_RST: U1.22 (IO14), U9.5 (RESET), U10.5 (RESET), U11.5 (RESET), U12.5 (RESET)
/DISP_SCLK: TP12.1, U1.20 (IO12), U9.8 (SCL), U10.8 (SCL), U11.8 (SCL), U12.8 (SCL)
/DISP_TOP_CS: U1.4 (IO4), U11.11 (CS)
/I2C_SCL: CAM1.5 (SIO_C), R1.2, TP9.1, U1.17 (IO9), U2.2 (SCL), U3.1 (SCL), U5.13 (SCL), U7.12 (SCL)
/I2C_SDA: CAM1.3 (SIO_D), R2.2, TP8.1, U1.12 (IO8), U2.1 (SDA), U3.4 (SDA), U5.14 (SDA), U7.13 (SDA)
/I2S_BCLK: MK1.4 (SCK), U1.9 (IO16), U13.16 (BCLK)
/I2S_LRCLK: MK1.1 (WS), U1.23 (IO21), U13.14 (LRCLK)
/I2S_MIC_DATA: MK1.6 (SD), R22.1, U1.33 (IO40)
/I2S_SPK_DATA: U1.35 (IO42), U13.1 (DIN)
/IMU_INT2: U1.11 (IO18), U5.9 (INT2)
/SERVO1_PWM: M1.1 (PWM), U1.39 (IO1)
/SERVO2_PWM: M2.1 (PWM), U1.38 (IO2)
/USB_CC1: J2.A5 (CC1), R4.1
/USB_CC2: J2.B5 (CC2), R3.1
/USB_D_N: J2.A7 (DN1), J2.B7 (DN2), U1.13 (IO19)
/USB_D_P: J2.A6 (DP1), J2.B6 (DP2), U1.14 (IO20)
/USB_VBUS: C1.1, J2.A4 (VBUS), J2.A9 (VBUS), J2.B4 (VBUS), J2.B9 (VBUS), TP2.1, U8.13 (IN)
GND: C1.2, C2.2, C3.2, C4.2, C5.2, C6.2, C7.2, C8.2, C9.2, C10.2, C11.2, CAM1.2 (AGND), CAM1.8 (PWDN), CAM1.15 (DGND), CAM1.MT1, CAM1.MT2, J1.1, J2.A1 (GND), J2.A12 (GND), J2.B1 (GND), J2.B12 (GND), J2.S_1, J2.S_2, J2.S_3, J2.S_4, M1.3 (-), M2.3 (-), MK1.2 (LR), MK1.3 (GND), Q1.2 (S), R3.2, R4.2, R5.2, R6.2, R7.2, R9.2, R22.2, R25.2, SW2.3, SW2.6, SW3.1, SW4.1, TH1.1, TP1.1, U1.1 (GND), U1.40 (GND), U1.41 (GND), U1.42 (GND), U1.43 (GND), U1.44 (GND), U1.45 (GND), U1.46 (GND), U1.47 (GND), U1.48 (GND), U1.49 (GND), U2.4 (VSS), U3.3 (GND), U4.B2 (GND), U5.1 (SDO/SA0), U5.6 (GND), U5.7 (GND), U7.6 (GND), U7.16 (ADDR), U7.17 (EPAD), U8.4 (*CE), U8.6 (EN1), U8.8 (VSS), U8.17 (EPAD), U9.3 (GND), U9.12 (GND), U9.P1, U9.P2, U10.3 (GND), U10.12 (GND), U10.P1, U10.P2, U11.3 (GND), U11.12 (GND), U11.P1, U11.P2, U12.3 (GND), U12.12 (GND), U12.P1, U12.P2, U13.2 (GAIN_SLOT), U13.3 (GND), U13.11 (GND), U13.15 (GND), U13.17 (EPAD), U14.2 (MODE), U14.3 (AGND), U14.8 (GND), U16.2 (GND)
LEDK: Q1.3 (D), U9.1 (LEDK), U10.1 (LEDK), U11.1 (LEDK), U12.1 (LEDK)
unnamed: C9.1, CAM1.4 (AVDD), U4.A2 (VOUT)
unnamed: C7.1, CAM1.10 (DVDD), U16.5 (OUT)
unnamed: CAM1.6 (RESET), R14.2
unnamed: R8.2, R11.1
unnamed: R16.1, SW2.2, SW2.5
unnamed: SW1.1, SW1.4
unnamed: R15.2, SW3.2, TP4.1, U1.3 (EN)
unnamed: R24.1, SW4.2, TP7.1, U1.27 (IO0)
unnamed: R20.2, U7.11 (*INT)
unnamed: R21.1, U7.1 (*RESET)
unnamed: R16.2, U7.4 (P2)
unnamed: R5.1, U8.12 (ILIM)
unnamed: R6.1, U8.16 (ISET)
unnamed: R7.1, U8.15 (ITERM)
unnamed: TH1.2, U8.1 (TS)
unnamed: R17.1, U9.2 (LEDA)
unnamed: R19.1, U10.2 (LEDA)
unnamed: R23.1, U11.2 (LEDA)
unnamed: R18.1, U12.2 (LEDA)
unnamed: LS1.1, U13.10 (OUTN)
unnamed: LS1.2, U13.9 (OUTP)
unnamed: R25.1, SW1.2, U14.1 (EN)
unnamed: R9.1, R11.2, U14.4 (FB)
unnamed: L1.1, U14.9 (L1)
unnamed: L1.2, U14.7 (L2)
unnamed: R10.2, U14.5 (PG)
unnamed: C2.1, SW1.5, TP5.1, U8.10 (OUT), U8.11 (OUT), U14.10 (VIN)

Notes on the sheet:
Buck, from battery voltage to 3.3v
Battery charge control
Amplifier for speaker
Temperature and humidity sensor
Mic
Servo motors
Short wavelength light sensor

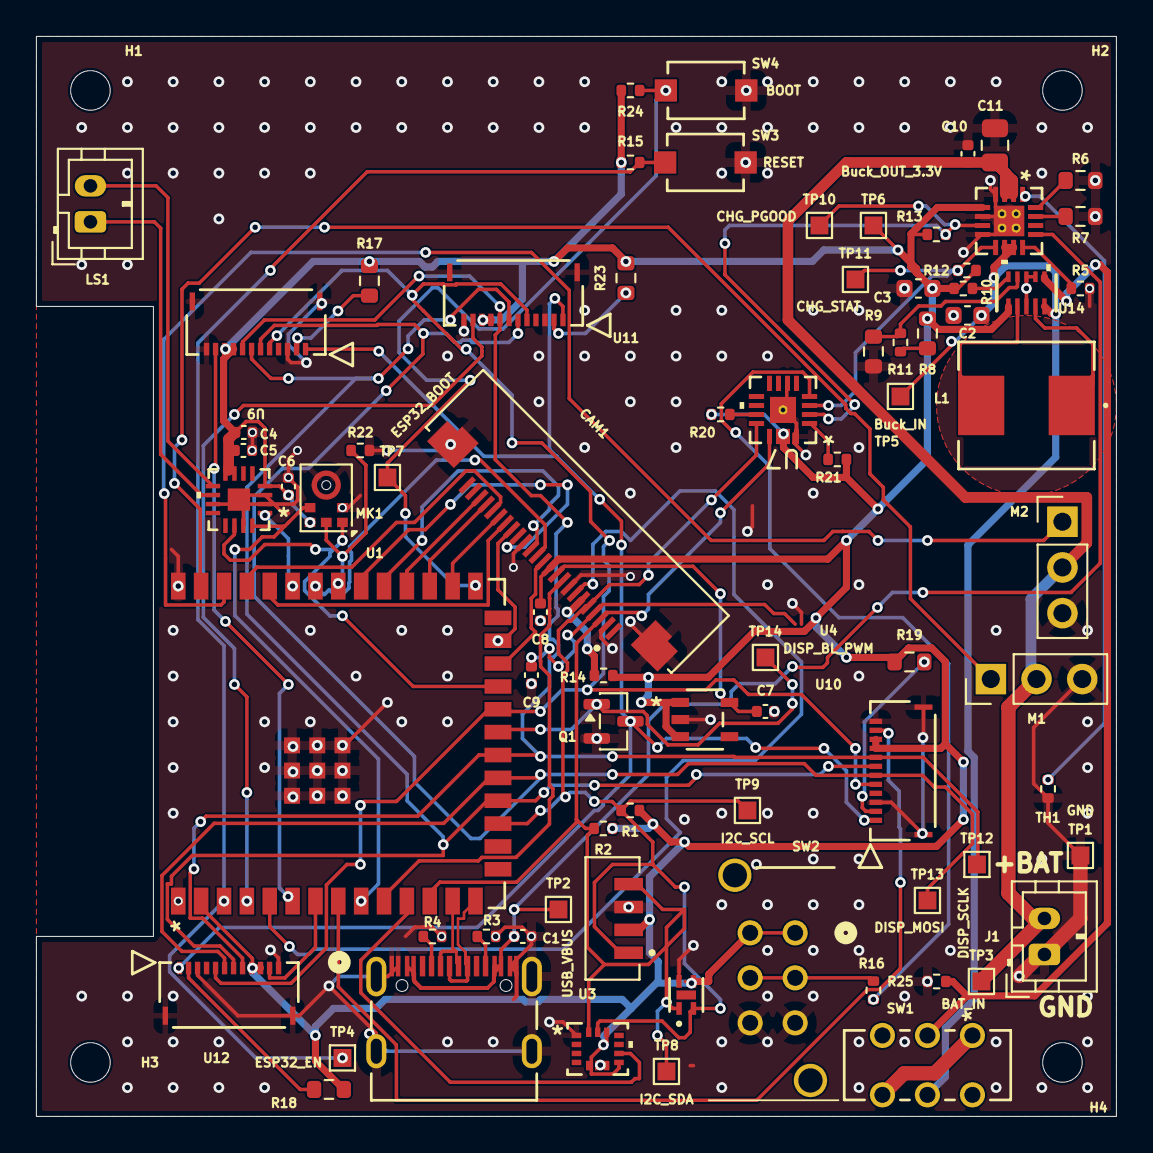
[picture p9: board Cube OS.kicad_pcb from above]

Board: 4 copper layers, 60.0 x 60.0 mm, 82 parts (0 on the bottom side), 68 nets.

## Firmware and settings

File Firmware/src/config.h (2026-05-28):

#pragma once

#define SERIAL_BAUD_RATE 115200

// Setup access point details. These are only used when the ESP32 needs Wi-Fi setup.
constexpr const char* AP_NAME = "CubeOS-Setup";
constexpr const char* AP_PASSWORD = "12345678";

// mDNS lets a browser open http://cubeos.local instead of typing the numeric IP address.
constexpr const char* MDNS_NAME = "cubeos";

// Names used inside ESP32 NVS flash storage for the saved Wi-Fi credentials.
constexpr const char* WIFI_NAMESPACE = "wifi";
constexpr const char* WIFI_SSID_KEY = "ssid";
constexpr const char* WIFI_PASSWORD_KEY = "password";
constexpr const char* WIFI_CONFIGURED_KEY = "configured";

// Timing values are in milliseconds.
constexpr unsigned long BOOT_STABILIZE_DELAY_MS = 3000;
constexpr unsigned long WIFI_CONNECT_TIMEOUT_MS = 15000;
constexpr unsigned long WIFI_CONNECT_CHECK_INTERVAL_MS = 500;
constexpr unsigned long MDNS_RETRY_INTERVAL_MS = 5000;

// The web server listens on port 80, the normal HTTP port.
constexpr int WEB_SERVER_PORT = 80;

constexpr int PIN_UNASSIGNED = -1;

// Rev A has no separate status LED GPIO in the schematic.
// Do not use GPIO48 for status LED: GPIO48 is CAM_PCLK.
constexpr int STATUS_LED_PIN = PIN_UNASSIGNED;

// Shared I2C/SCCB bus.
constexpr int I2C_SDA_PIN = 8;
constexpr int I2C_SCL_PIN = 9;

// Four display connectors share MOSI/SCLK/DC/reset/backlight and use separate CS pins.
constexpr int DISPLAY_TOP_CS_PIN = 4;
constexpr int DISPLAY_FRONT_CS_PIN = 6;
constexpr int DISPLAY_LEFT_CS_PIN = 7;
constexpr int DISPLAY_RIGHT_CS_PIN = 15;
constexpr int DISPLAY_DC_PIN = 10;
constexpr int DISPLAY_MOSI_PIN = 11;
constexpr int DISPLAY_SCLK_PIN = 12;
constexpr int DISPLAY_BACKLIGHT_PWM_PIN = 13;
constexpr int DISPLAY_RESET_PIN = 14;

// I2S audio: ICS-43434 microphone and MAX98357A speaker amplifier.
constexpr int I2S_BCLK_PIN = 16;
constexpr int I2S_LRCLK_PIN = 21;
constexpr int I2S_MIC_DATA_PIN = 40;
constexpr int I2S_SPK_DATA_PIN = 42;

// ISM330DHCX interrupt lines.
// INT1 is not connected in the latest Rev A schematic.
constexpr int IMU_INT1_PIN = PIN_UNASSIGNED;
constexpr int IMU_INT2_PIN = 18;

// Servo connector PWM pins.
constexpr int MOVEMENT_SERVO1_PWM_PIN = 1; // M1
constexpr int MOVEMENT_SERVO2_PWM_PIN = 2; // M2

// Only assign these after confirming which physical servo is left/right.
constexpr int MOVEMENT_LEFT_SERVO_PIN = PIN_UNASSIGNED;
constexpr int MOVEMENT_RIGHT_SERVO_PIN = PIN_UNASSIGNED;

// User/control and charger status lines are on the TCA6408 I2C GPIO expander,
// not direct ESP32 GPIOs.
constexpr int USER_SWITCH_PIN = PIN_UNASSIGNED;
constexpr int CHARGER_PGOOD_PIN = PIN_UNASSIGNED;
constexpr int CHARGER_STAT_PIN = PIN_UNASSIGNED;

constexpr int IO_EXPANDER_CHARGER_PGOOD_PIN = 0;
constexpr int IO_EXPANDER_CHARGER_STAT_PIN = 1;
constexpr int IO_EXPANDER_USER_SWITCH_PIN = 2;

// OV2640 camera parallel bus and clock/sync pins.
constexpr int CAMERA_D0_PIN = 35;
constexpr int CAMERA_D1_PIN = 36;
constexpr int CAMERA_D2_PIN = 37;
constexpr int CAMERA_D3_PIN = 43; // schematic pin function TXD0
constexpr int CAMERA_D4_PIN = 44; // schematic pin function RXD0
constexpr int CAMERA_D5_PIN = 39;
constexpr int CAMERA_D6_PIN = 38;
constexpr int CAMERA_D7_PIN = 47;
constexpr int CAMERA_HREF_PIN = 17;
constexpr int CAMERA_PCLK_PIN = 48;
constexpr int CAMERA_VSYNC_PIN = 5;
constexpr int CAMERA_XCLK_PIN = 41;
constexpr int CAMERA_RESET_PIN = PIN_UNASSIGNED; // pulled up by R14
constexpr int CAMERA_PWDN_PIN = PIN_UNASSIGNED;  // tied to GND

// Native USB pins. Keep these reserved for USB.
constexpr int USB_D_N_PIN = 19;
constexpr int USB_D_P_PIN = 20;

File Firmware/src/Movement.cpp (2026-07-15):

#include <Arduino.h>

#include "Movement.h"
#include "config.h"

// This file is for motor and walking code.
// Right now, only a very small motor test is active.
// The more complicated walking and IMU balance ideas are saved below as commented-out future code.

namespace {

// Servos normally expect a control signal repeated about 50 times per second.
// That is why the PWM frequency is 50 Hz.
constexpr int SERVO_PWM_FREQUENCY_HZ = 50;

// PWM resolution controls how many tiny steps the ESP32 can use for the signal.
// 14 bits gives values from 0 to 16383 and fits the ESP32-S3 LEDC limit at 50 Hz.
constexpr int SERVO_PWM_RESOLUTION_BITS = 14;

// LEDC is the ESP32 PWM system.
// Each servo gets its own PWM channel, like a separate output lane.
constexpr int SERVO1_PWM_CHANNEL = 0;
constexpr int SERVO2_PWM_CHANNEL = 1;

// Servo pulses are measured in microseconds.
// For many servos:
// - 1500 us is center / stop / neutral
// - 1300 us moves one direction
// - 1700 us moves the other direction
// These are gentle test values. If the motor moves too far, use values closer to 1500.
constexpr int SERVO_LOW_TEST_PULSE_US = 1300;
constexpr int SERVO_CENTER_PULSE_US = 1500;
constexpr int SERVO_HIGH_TEST_PULSE_US = 1700;

// How long each simple motor test position is held.
// 1000 ms = 1 second.
constexpr unsigned long SIMPLE_MOTOR_TEST_HOLD_MS = 1000;

// Converts a servo pulse length, like 1500 us, into the duty value that ledcWrite() needs.
// The ESP32 LEDC function does not take microseconds directly, so this helper does the math.
uint32_t servoPulseToDuty(int pulseUs) {
  const uint32_t maxDuty = (1UL << SERVO_PWM_RESOLUTION_BITS) - 1;
  return (static_cast<uint64_t>(pulseUs) * maxDuty * SERVO_PWM_FREQUENCY_HZ) / 1000000ULL;
}

// Sends one servo pulse setting to one PWM channel.
// Example: writeServoPulse(SERVO1_PWM_CHANNEL, 1500) puts motor 1 at center.
void writeServoPulse(int channel, int pulseUs) {
  ledcWrite(channel, servoPulseToDuty(pulseUs));
}

// Puts both motors into their neutral position.
// This is the safest place to start and finish a motor test.
void centerMotors() {
  writeServoPulse(SERVO1_PWM_CHANNEL, SERVO_CENTER_PULSE_US);
  writeServoPulse(SERVO2_PWM_CHANNEL, SERVO_CENTER_PULSE_US);
}

// This is the only movement test that currently runs.
// It does not try to walk yet. It only checks that each motor responds.
void runSimpleMotorTest() {
  // Step 1: Start both motors at center so nothing suddenly moves at boot.
  Serial.println("Simple motor test: center M1 and M2.");
  centerMotors();
  delay(SIMPLE_MOTOR_TEST_HOLD_MS);

  // Step 2: Move only M1 while M2 stays centered.
  Serial.println("Simple motor test: move M1.");
  writeServoPulse(SERVO1_PWM_CHANNEL, SERVO_LOW_TEST_PULSE_US);
  writeServoPulse(SERVO2_PWM_CHANNEL, SERVO_CENTER_PULSE_US);
  delay(SIMPLE_MOTOR_TEST_HOLD_MS);

  // Step 3: Return both motors to center before testing the next motor.
  Serial.println("Simple motor test: center M1 and M2.");
  centerMotors();
  delay(SIMPLE_MOTOR_TEST_HOLD_MS);

  // Step 4: Move only M2 while M1 stays centered.
  Serial.println("Simple motor test: move M2.");
  writeServoPulse(SERVO1_PWM_CHANNEL, SERVO_CENTER_PULSE_US);
  writeServoPulse(SERVO2_PWM_CHANNEL, SERVO_HIGH_TEST_PULSE_US);
  delay(SIMPLE_MOTOR_TEST_HOLD_MS);

  // Step 5: Finish centered so the robot is not left trying to move.
  Serial.println("Simple motor test done. Holding center.");
  centerMotors();
}

}

/*
  Future walking sequence section.
  This is commented out while the simple motor test is active.

  The idea here is to make the motor values change over time:

    1300 -> 1500 -> 1700 -> 1500 -> repeat

  That is closer to walking than holding one fixed motor value forever.

  constexpr unsigned long BASIC_WALK_STEP_INTERVAL_MS = 1200;
  constexpr int BASIC_WALK_STEP_COUNT = 4;

  const int SERVO1_WALK_SEQUENCE_US[BASIC_WALK_STEP_COUNT] = {
    SERVO_LOW_TEST_PULSE_US,
    SERVO_CENTER_PULSE_US,
    SERVO_HIGH_TEST_PULSE_US,
    SERVO_CENTER_PULSE_US,
  };

  const int SERVO2_WALK_SEQUENCE_US[BASIC_WALK_STEP_COUNT] = {
    SERVO_HIGH_TEST_PULSE_US,
    SERVO_CENTER_PULSE_US,
    SERVO_LOW_TEST_PULSE_US,
    SERVO_CENTER_PULSE_US,
  };

  int currentWalkStep = 0;
  unsigned long lastWalkStepAt = 0;

  void writeBasicWalkStep(int stepIndex) {
    writeServoPulse(SERVO1_PWM_CHANNEL, SERVO1_WALK_SEQUENCE_US[stepIndex]);
    writeServoPulse(SERVO2_PWM_CHANNEL, SERVO2_WALK_SEQUENCE_US[stepIndex]);
  }

  void updateBasicWalking() {
    if (millis() - lastWalkStepAt < BASIC_WALK_STEP_INTERVAL_MS) {
      return;
    }

    lastWalkStepAt = millis();
    writeBasicWalkStep(currentWalkStep);
    currentWalkStep = (currentWalkStep + 1) % BASIC_WALK_STEP_COUNT;
  }
*/
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

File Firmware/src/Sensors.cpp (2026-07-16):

#include <Arduino.h>
#include <Wire.h>
#include <Adafruit_ISM330DHCX.h>

#include "Sensors.h"
#include "config.h"

namespace {

    constexpr uint8_t IMU_ADDRESS = 0x6A; // I2C address for ISM330DHCX
    constexpr unsigned long IMU_PRINT_INTERVAL_MS = 250;

    Adafruit_ISM330DHCX imu;

    bool imuReady = false;
    unsigned long lastImuPrintTime = 0;

    const char* i2cDeviceName(uint8_t address) {
        switch (address) {
            case 0x10:
                return "VEML7700 light sensor";
            case 0x20:
                return "TCA6408 GPIO expander";

            case 0x44:
                return "SHT45 temperature/humidity sensor";

            case 0x6A:
                return "ISM330DHCX IMU";

            default:
                return "Unknown device";
        }
    }
}

void scanI2CBus() {
    Serial.println("Scanning I2C bus for devices...");

    Serial.println("I2C devices found:");

    int deviceCount = 0;

    for (uint8_t address = 1; address < 127; address++) {
        Wire.beginTransmission(address);
        uint8_t result = Wire.endTransmission();

        if (result == 0) {
            Serial.print("Found 0x");
            Serial.print(address, HEX);
            Serial.print(": ");
            Serial.println(i2cDeviceName(address));
            deviceCount++;
        }
        delay(2); // Short delay between address checks
    }
    Serial.print("Total devices found: ");
    Serial.println(deviceCount);
}

void setupSensors() {
    Serial.println("Starting I2C bus...");

    bool started = Wire.begin(I2C_SDA_PIN, I2C_SCL_PIN, 100000);
    if (!started) {
        Serial.println("Failed to start I2C bus.");
        return;
    }
    delay(100); // Give some time for devices to power up

    scanI2CBus();

    Serial.println("Starting ISM330DHCX IMU...");

    if (!imu.begin_I2C(IMU_ADDRESS, &Wire)) {
        Serial.println("Failed to initialize ISM330DHCX");
        return;
    }

    // ±4 g is suitable for basic tilt and movement testing.
    imu.setAccelRange(LSM6DS_ACCEL_RANGE_4_G);
    // ±500 degrees per second is suitable for movement by hand.
    imu.setGyroRange(LSM6DS_GYRO_RANGE_500_DPS);

    // Read both sensors internally at 104 samples per second.
    imu.setAccelDataRate(LSM6DS_RATE_104_HZ);
    imu.setGyroDataRate(LSM6DS_RATE_104_HZ);

    imuReady = true;

    Serial.println("ISM330DHCX IMU initialized successfully.");
}

void updateSensors() {
    if (!imuReady) {
        return;
    }

    unsigned long now = millis();
    if (now - lastImuPrintTime < IMU_PRINT_INTERVAL_MS) {
        return;
    }

    lastImuPrintTime = now;
    sensors_event_t acceleration;
    sensors_event_t gyro;
    sensors_event_t temperature;

    if (!imu.getEvent(&acceleration, &gyro, &temperature)) {
        Serial.println("Failed to read from ISM330DHCX IMU.");
        return;
    }
    Serial.print("Accel m/s^2 — X: ");
    Serial.print(acceleration.acceleration.x, 2);
    Serial.print("  Y: ");
    Serial.print(acceleration.acceleration.y, 2);
    Serial.print("  Z: ");
    Serial.print(acceleration.acceleration.z, 2);

    Serial.print(" | Gyro rad/s — X: ");
    Serial.print(gyro.gyro.x, 2);
    Serial.print("  Y: ");
    Serial.print(gyro.gyro.y, 2);
    Serial.print("  Z: ");
    Serial.print(gyro.gyro.z, 2);

    Serial.print(" | Temperature: ");
    Serial.print(temperature.temperature, 2);
    Serial.println(" C");
}

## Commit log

2026-05-08 Scaffold hardware project repo
    [BOM_JLCPCB.csv, CubeOS.kicad_pcb, CubeOS.kicad_sch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]
2026-05-10 reorganised V2 linkage and uploaded V1 linkage for version iterations
    [B1.step, B2.step, B3.step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]
2026-05-11 Add Rev A hardware files and concise docs
    [21-0896B_9_MXM.step, AMPLA7030SR47MT--3DModel-STEP-368357.STEP, BOM.csv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]
2026-05-11 Update README with current status photos
2026-05-18 Update Rev A hardware files
    [5034801200.stp, BOM.csv, Cube OS component sheet - N8R2 plan.xlsx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]
2026-05-18 Add ESP32 Wi-Fi dashboard setup flow
2026-05-19 Add Rev A pin map guide
2026-05-19 Modularize firmware runtime
    Split dashboard, network, movement, and boot orchestration into separate modules.
    Add Rev A pin constants, IMU library dependencies, and initial servo movement test hooks.
2026-05-23 Update firmware pin map for Rev A
2026-05-23 Update Rev A PCB production package
    [5034801200.stp, BOM.csv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]
2026-05-23 Revert "Update Rev A PCB production package"
    This reverts commit 683648053a19518fab4d864910172dd1a356c20e.
    [5034801200.stp, BOM.csv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]
2026-05-28 Add Rev A order package docs
    [BOM_manufacture.xls]
2026-05-28 Update project assets and LFS tracking
    [21-0896B_9_MXM.step, 5034801200.stp, AMPLA7030SR47MT--3DModel-STEP-368357.STEP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]
2026-05-28 added linkage v3 and body files
    [Body.step, Front Lower Link.step, Front Triangle Coupler.step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]
2026-07-15 firmware: configure Rev A ESP32-S3 target
2026-07-16 firmware: add I2C scan and IMU diagnostics
2026-07-16 docs: record PWM and sensor bring-up
